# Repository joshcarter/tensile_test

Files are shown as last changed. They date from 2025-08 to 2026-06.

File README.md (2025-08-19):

# 3D Printed Plastic Tensile Strength

## Overview

I use this for measuring the tensile strength of 3D printed plastics.
There is a test fixture, an interface board, and program that runs on
a nearby laptop.

## Test Fixture

- Hi-Lift Jack
- Two clamps (see `printed_parts/Clamp.3mf`)
- 500kg S-type load cell
- HX711 load cell amplifier
- Rasperry Pi Pico interface board
- Laptop with USB connection to interface board

## Test Fixture Assembly

TODO: photo and instructions.

## Test Samples

See `printed_parts/Tensile test samples.3mf`. Note that the Z axis has
additional cross-sectional area since the Z axis is usually
substantially weaker.

## Interface Board

- Sparkfun HX711 load cell amplifier
- Raspberry Pi Pico

TODO: circuit schematic

The MicroPython code for the Pico is in the `pico` subdirectory.

## Python Requirements

    pip install -r requirements.txt

## Test Fixture Calibration

Initially the fixture will not be calibrated. Load code on the Pi Pico
(`pico/*.py) and it will output raw readings from the HX711.

Find some number of known calibration weights. I used kettlebells and
used a hanging scale to measure them as accurately as possible. These
readings (in KG) go into the `CAL_WEIGHTS` list in `utils.py`.

Run the calibration:

    python tensile_test.py calibrate --port /dev/cu.usbserial101

The first "known weight" should be no weight except the printed clamp.
Then add each known weight, pressing enter when the fixture is steady.

Finally, a `calibration.json` file will be written to this directory.
That file should be copied to the Pico. Once the Pico has its
calibration file it will output Newtons of force instead of raw HX711
readings.

## Running Tensile Tests

The main program is run like so:

    python tensile_test.py test \
      --port /dev/cu.usbserial101 \
      --type "PETG-CF" \
      --manufacturer "Atomic Filament" \
      --color "black" \
      --axis xy \

All test data will be output to a directory in the `data`
subdirectory, plus summary stats will be collected in `data/data.csv`.

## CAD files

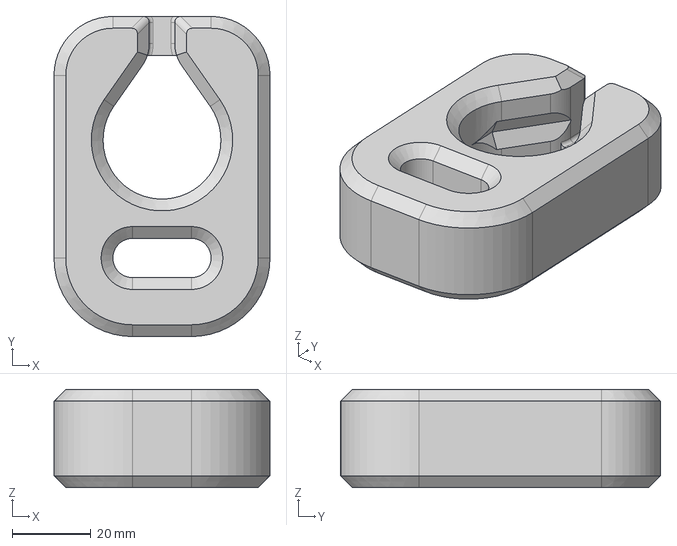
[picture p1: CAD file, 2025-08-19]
printed_parts/step/Clamp.step
55.0 x 81.5 x 25.0 mm

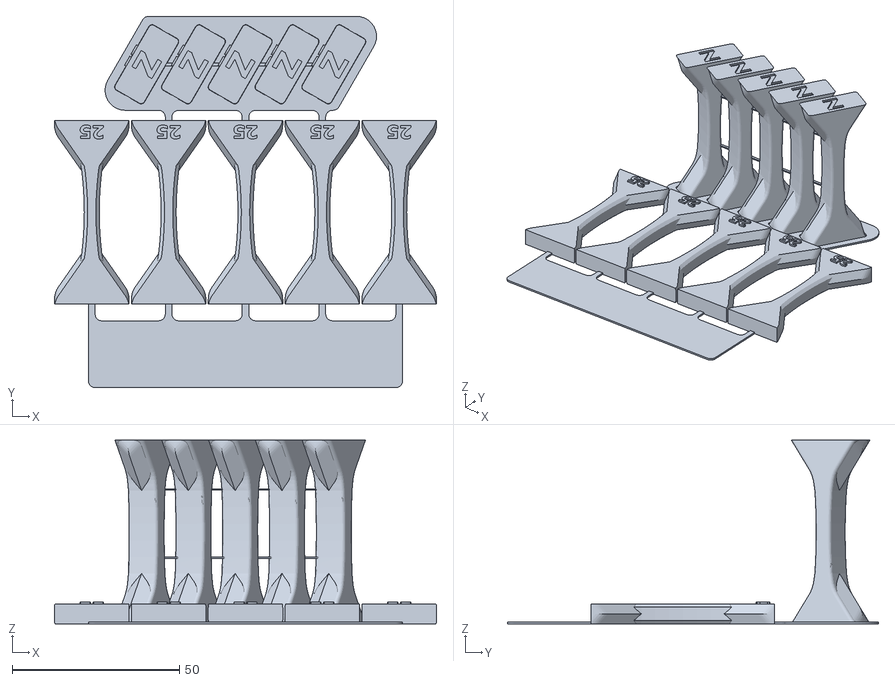
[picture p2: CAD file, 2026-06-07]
printed_parts/stl/Tensile test samples XY 25 Z 50 C.stl
114.3 x 111.1 x 55.0

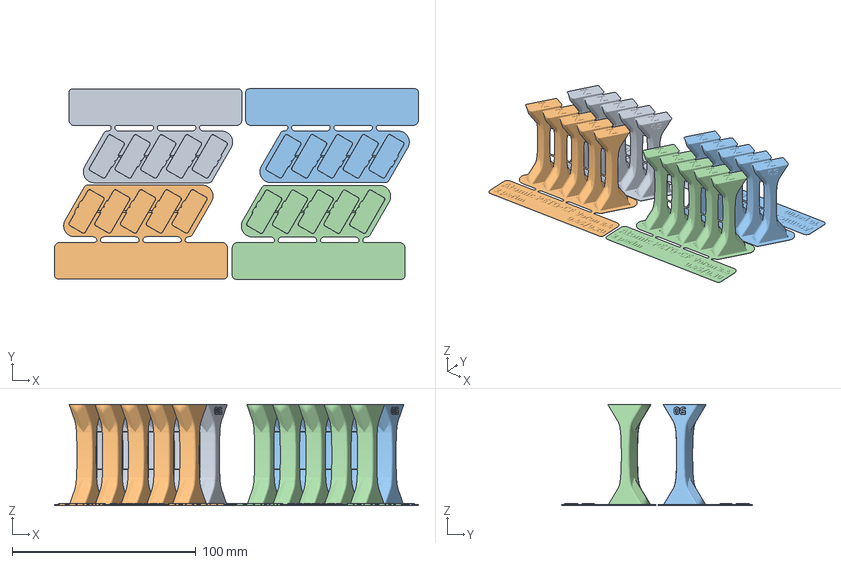
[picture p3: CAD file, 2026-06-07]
printed_parts/Tensile test samples-Z tests.3mf
197.9 x 103.6 x 55.0 mm
10 perim 0.45 0.20
2 perim 0.45 0.20
10 perim 0.45 0.10
2 perim 0.45 0.10

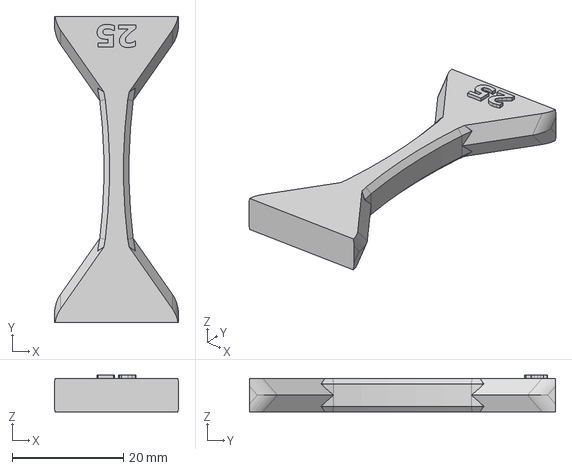
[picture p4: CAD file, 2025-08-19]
printed_parts/step/Tester XY 25mm2.step
22.3 x 55.0 x 6.60 mm

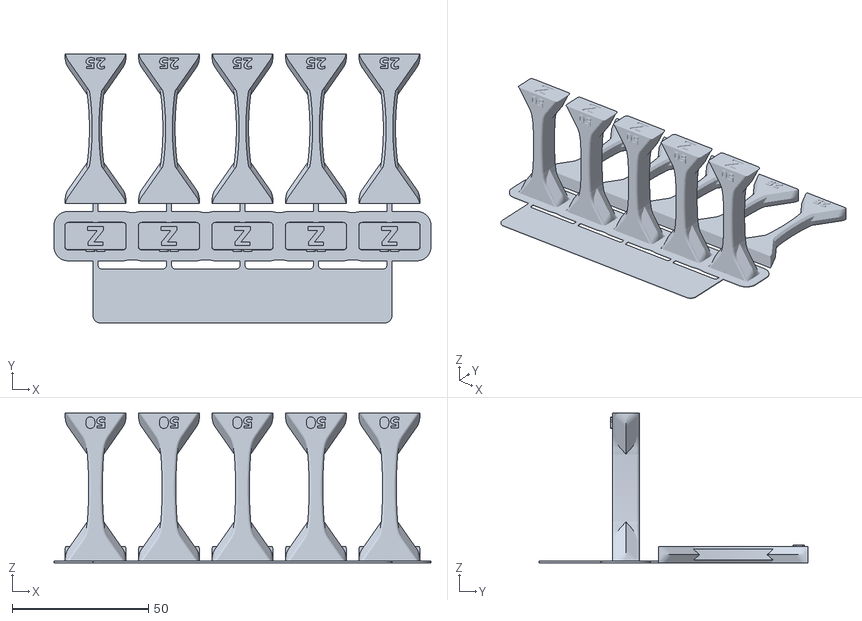
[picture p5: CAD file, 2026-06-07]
printed_parts/stl/Tensile test samples XY 25mm2 Z 50mm2 brim.stl
138.5 x 99.0 x 55.0

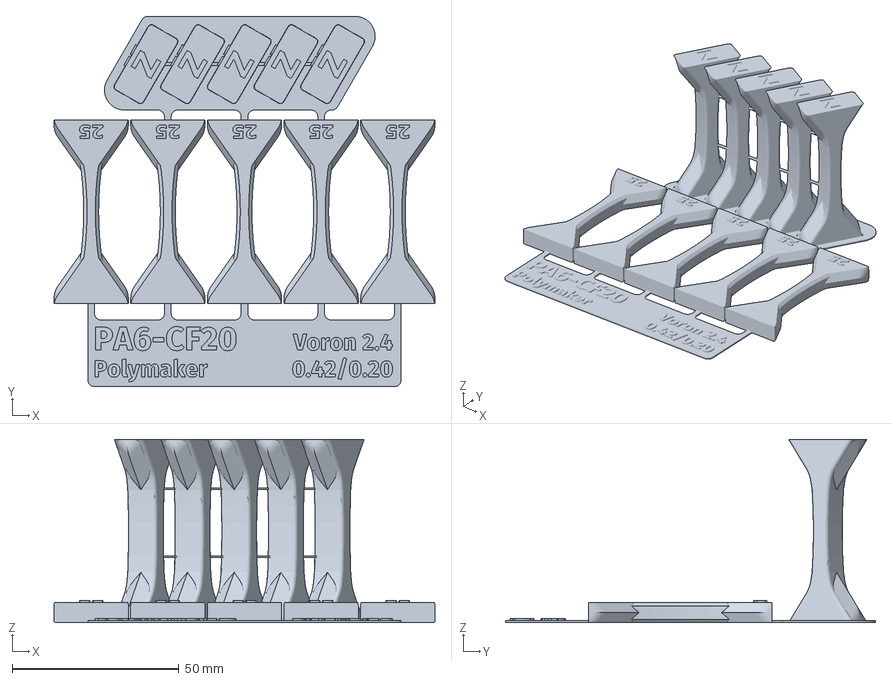
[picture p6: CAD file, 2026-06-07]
printed_parts/Tensile test samples.3mf
114.3 x 111.1 x 55.0 mm

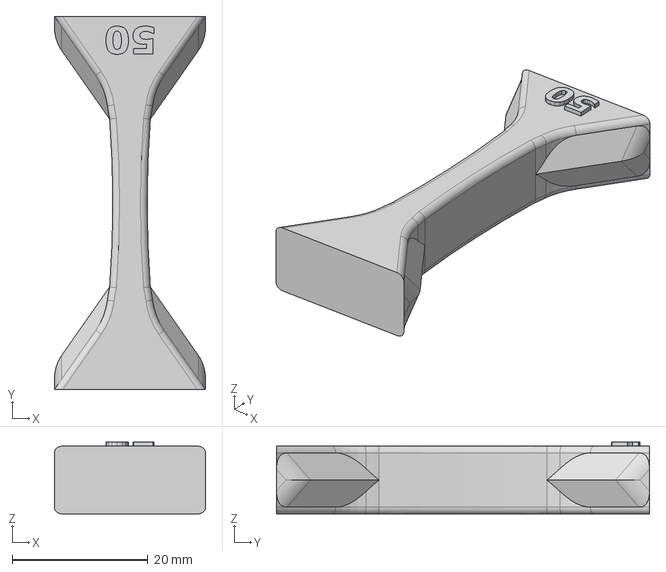
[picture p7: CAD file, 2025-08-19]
printed_parts/step/Tester Z 50mm2.step
22.3 x 55.0 x 10.6 mm

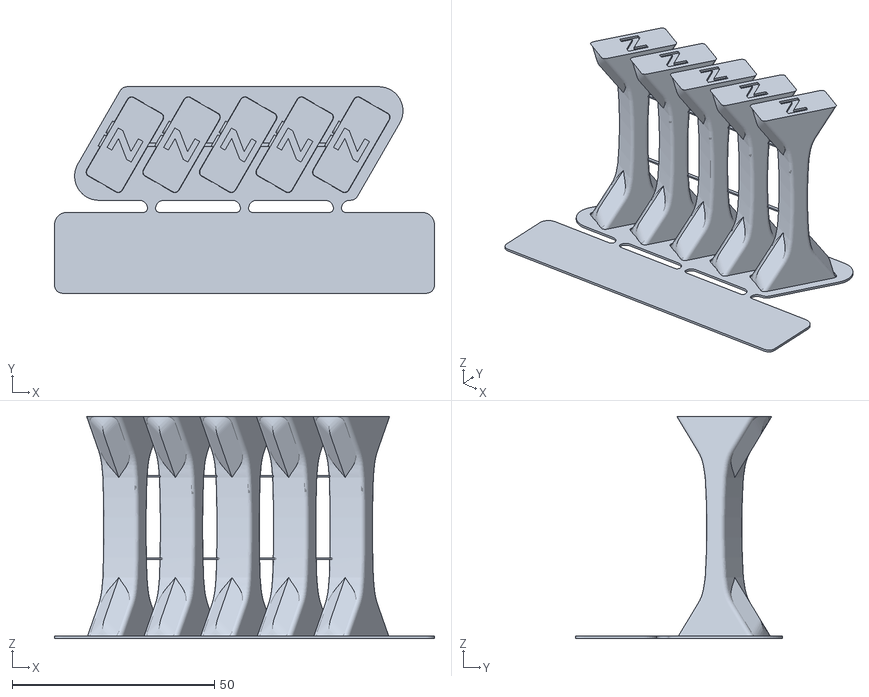
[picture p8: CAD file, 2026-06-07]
printed_parts/stl/Tensile test Z only.stl
94.0 x 51.1 x 55.0

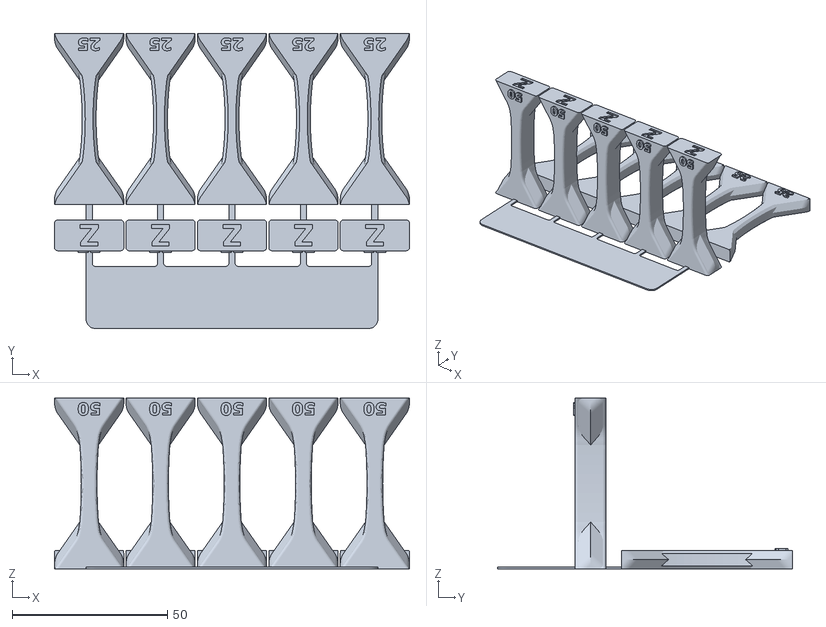
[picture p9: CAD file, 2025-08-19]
printed_parts/stl/Tensile test samples XY 25mm2 Z 50mm2.stl
114.3 x 95.0 x 55.0

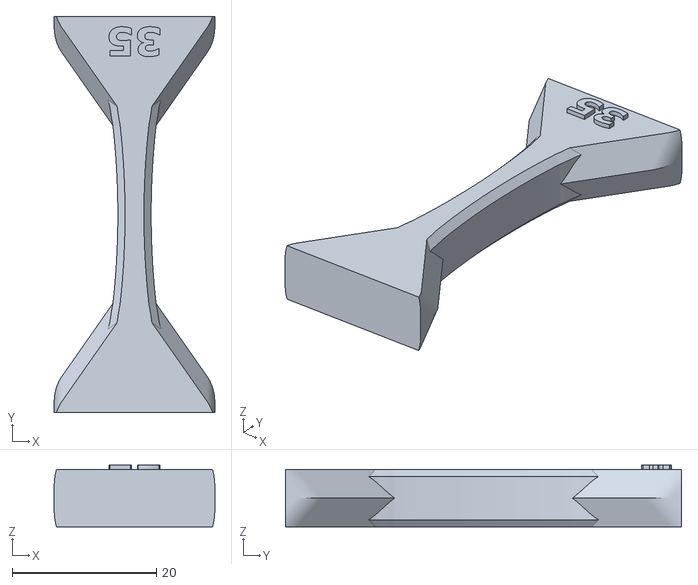
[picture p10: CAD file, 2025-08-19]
printed_parts/stl/Tester XY 35mm2.stl
22.3 x 55.0 x 8.60

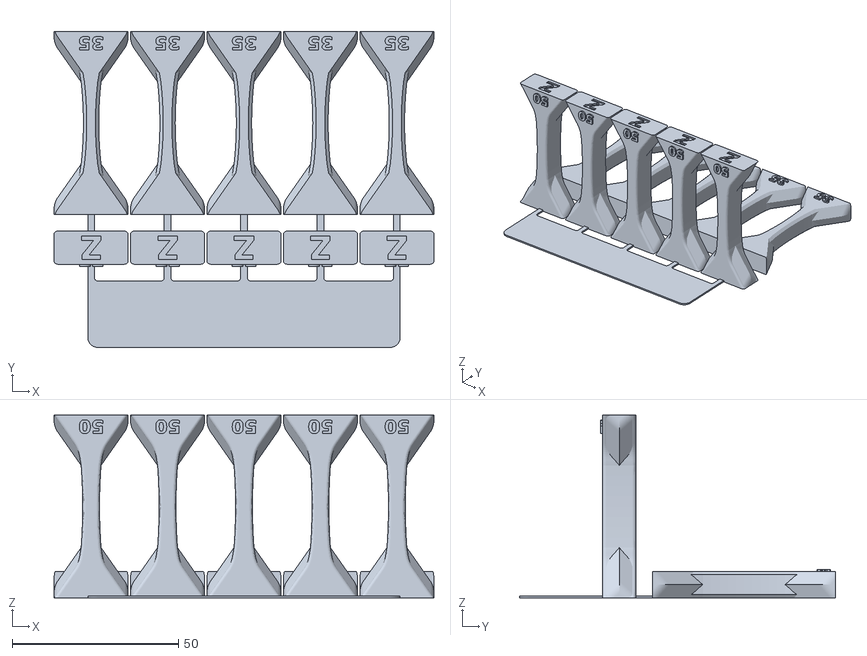
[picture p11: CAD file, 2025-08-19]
printed_parts/stl/Tensile test samples XY 35mm2 Z 50mm2.stl
114.3 x 95.0 x 55.0

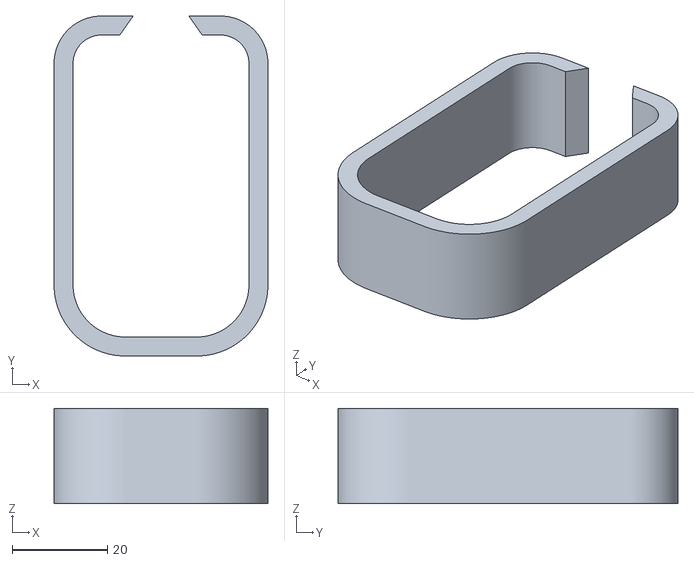
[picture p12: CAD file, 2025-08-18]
printed_parts/stl/Clamp - perim modifier.stl
45.0 x 71.5 x 20.0

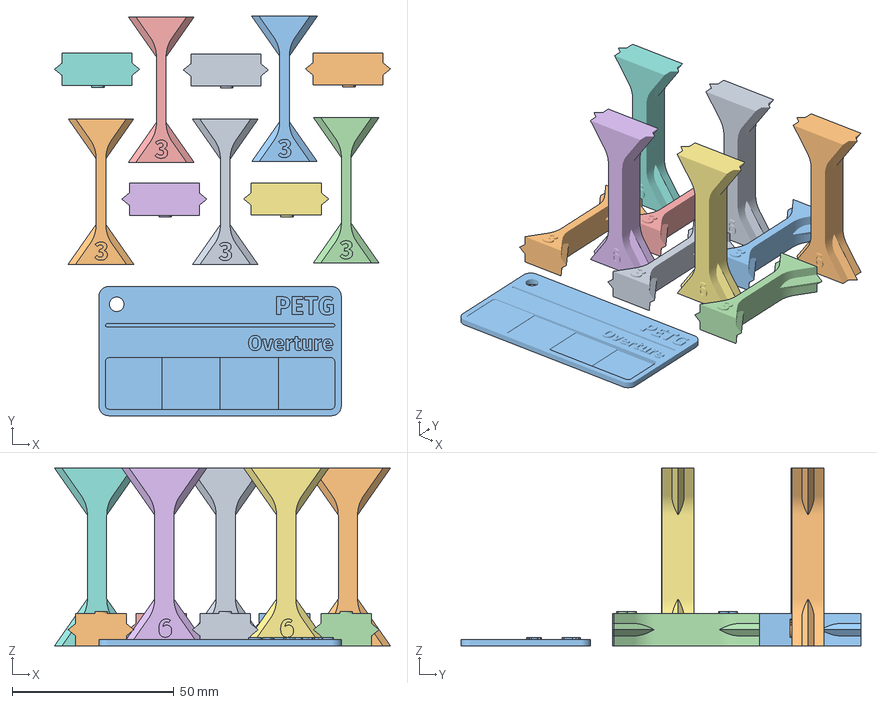
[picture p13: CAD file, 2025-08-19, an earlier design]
printed_parts/old/Tensile test samples larger [P40].3mf
104.0 x 123.6 x 55.0 mm
Tester (30mm2).stl
Tester (60mm2).stl
Sample chip

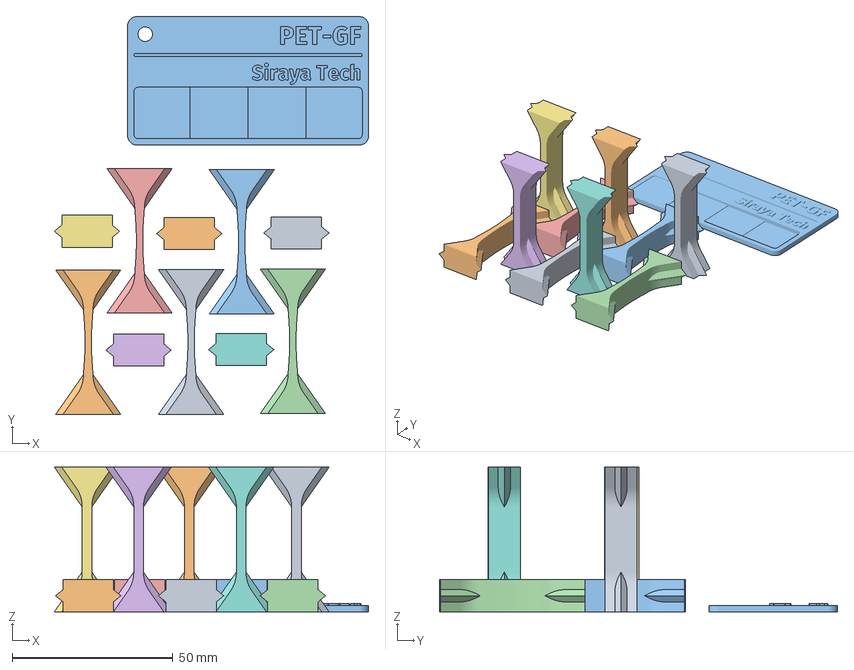
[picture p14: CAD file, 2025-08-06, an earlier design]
printed_parts/old/Tensile test samples [Mk3].3mf
97.8 x 123.8 x 45.0 mm
Tester (20mm2).stl
Tester (30mm2).stl
Sample chip

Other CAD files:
printed_parts/stl/Tensile test samples XY 25 Z 50 B.stl
printed_parts/old/Tensile test samples larger [V40].3mf
printed_parts/old/Tensile test samples larger [XL5].3mf
printed_parts/old/Tensile test samples [V40 thick extrusion].3mf
printed_parts/Clamp.3mf
printed_parts/fusion/Tensile test new design v10.f3d
printed_parts/fusion/Tensile test print setup v5.f3z
printed_parts/old/Tensile test samples [XL5].3mf
printed_parts/stl/Clamp.stl
printed_parts/stl/Tester XY 25mm2.stl
printed_parts/stl/Tester Z 50mm2.stl

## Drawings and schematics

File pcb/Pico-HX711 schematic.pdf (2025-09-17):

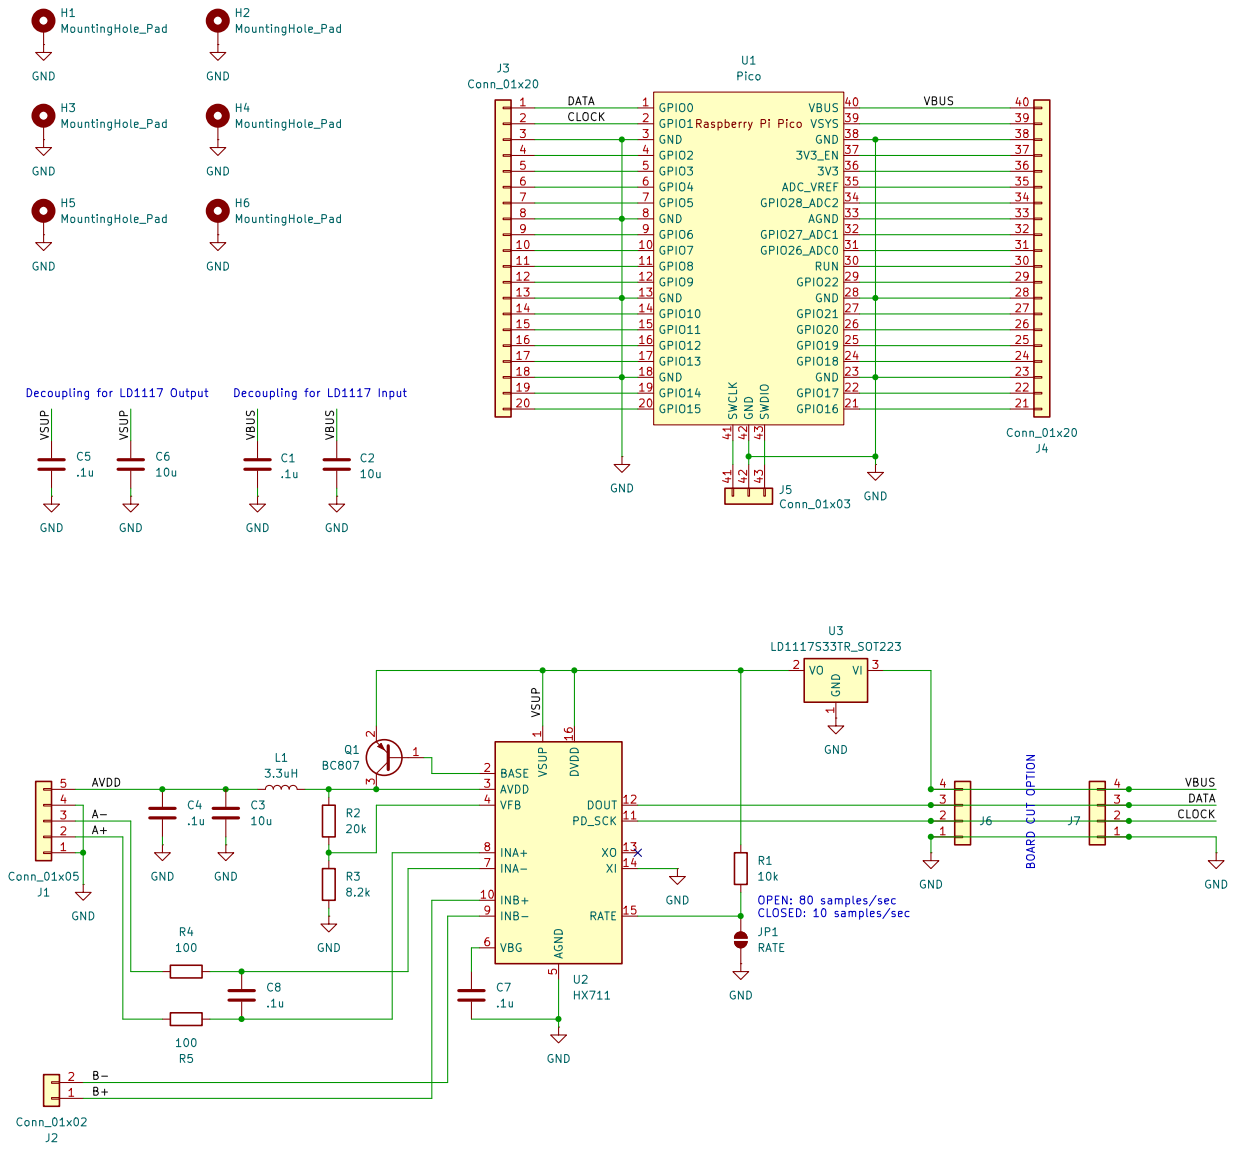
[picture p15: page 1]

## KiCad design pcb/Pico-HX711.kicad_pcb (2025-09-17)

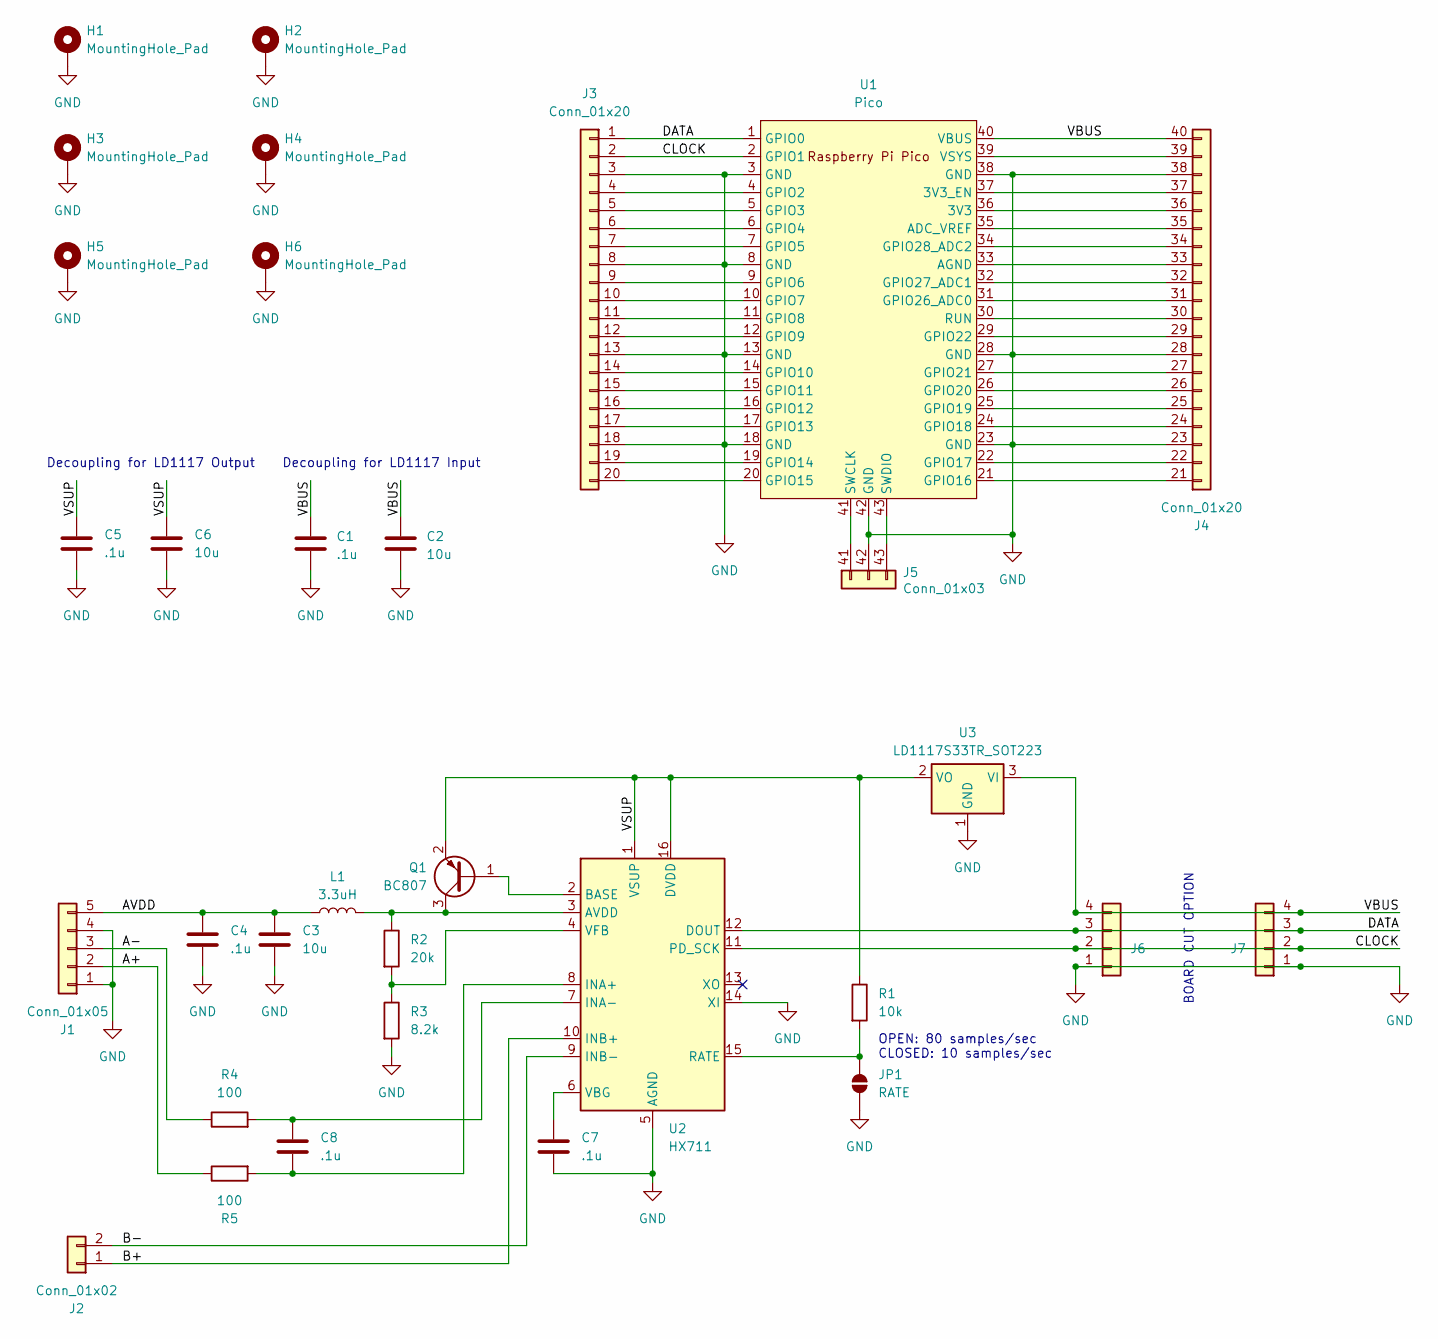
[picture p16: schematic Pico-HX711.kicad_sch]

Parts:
C1, C4, C5, C7, C8: .1u; C_0603_1608Metric
C2, C3, C6: 10u; C_1210_3225Metric
H1, H2, H3, H4, H5, H6: MountingHole_Pad; MountingHole_2.7mm_M2.5_Pad
J1: Conn_01x05; PinHeader_1x05_P2.54mm_Vertical
J2: Conn_01x02; PinHeader_1x02_P2.54mm_Vertical
J3: Conn_01x20; Pico_header_1
J4: Conn_01x20; Pico_header_2
J5: Conn_01x03; Pico_header_3
J6, J7: Conn_01x04; PinHeader_1x04_P2.54mm_Vertical
JP1: RATE; SolderJumper-2_P1.3mm_Open_RoundedPad1.0x1.5mm
L1: 3.3uH; L_0805_2012Metric
Q1: BC807; SOT-23
R1: 10k; R_0603_1608Metric
R2: 20k; R_0603_1608Metric
R3: 8.2k; R_0603_1608Metric
R4, R5: 100; R_0603_1608Metric
U1: Pico; RPi_Pico_SMD_TH
U2: HX711; SOIC-16_3.9x9.9mm_P1.27mm
U3: LD1117S33TR_SOT223; SOT-223-3_TabPin2

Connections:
/A+: J1.2, R5.1
/A-: J1.3, R4.1
/AVDD: C3.1, C4.1, J1.5, L1.1
/B+: J2.1, U2.10 (INB+)
/B-: J2.2, U2.9 (INB-)
/CLOCK: J3.2, J6.2, J7.2, U1.2 (GPIO1), U2.11 (PD_SCK)
/DATA: J3.1, J6.3, J7.3, U1.1 (GPIO0), U2.12 (DOUT)
/VBUS: C1.2, C2.2, J4.40 (Pin_20), J6.4, J7.4, U1.40 (VBUS), U3.3 (VI)
/VSUP: C5.1, C6.1, Q1.2 (E), R1.1, U2.1 (VSUP), U2.16 (DVDD), U3.2 (VO)
GND: C1.1, C2.1, C3.2, C4.2, C5.2, C6.2, C7.2, H1.1, H2.1, H3.1, H4.1, H5.1, H6.1, J1.1, J1.4, J3.3, J3.8, J3.13, J3.18, J4.23 (Pin_3), J4.28 (Pin_8), J4.38 (Pin_18), J5.42 (Pin_2), J6.1, J7.1, JP1.1 (A), R3.2, U1.3 (GND), U1.8 (GND), U1.13 (GND), U1.18 (GND), U1.23 (GND), U1.28 (GND), U1.38 (GND), U1.42 (GND), U2.5 (AGND), U2.14 (XI), U3.1 (GND)
unnamed: J3.4, U1.4 (GPIO2)
unnamed: J3.5, U1.5 (GPIO3)
unnamed: J3.6, U1.6 (GPIO4)
unnamed: J3.7, U1.7 (GPIO5)
unnamed: J3.9, U1.9 (GPIO6)
unnamed: J3.10, U1.10 (GPIO7)
unnamed: J3.11, U1.11 (GPIO8)
unnamed: J3.12, U1.12 (GPIO9)
unnamed: J3.14, U1.14 (GPIO10)
unnamed: J3.15, U1.15 (GPIO11)
unnamed: J3.16, U1.16 (GPIO12)
unnamed: J3.17, U1.17 (GPIO13)
unnamed: J3.19, U1.19 (GPIO14)
unnamed: J3.20, U1.20 (GPIO15)
unnamed: J4.21 (Pin_1), U1.21 (GPIO16)
unnamed: J4.22 (Pin_2), U1.22 (GPIO17)
unnamed: J4.24 (Pin_4), U1.24 (GPIO18)
unnamed: J4.25 (Pin_5), U1.25 (GPIO19)
unnamed: J4.26 (Pin_6), U1.26 (GPIO20)
unnamed: J4.27 (Pin_7), U1.27 (GPIO21)
unnamed: J4.29 (Pin_9), U1.29 (GPIO22)
unnamed: J4.30 (Pin_10), U1.30 (RUN)
unnamed: J4.31 (Pin_11), U1.31 (GPIO26_ADC0)
unnamed: J4.32 (Pin_12), U1.32 (GPIO27_ADC1)
unnamed: J4.33 (Pin_13), U1.33 (AGND)
unnamed: J4.34 (Pin_14), U1.34 (GPIO28_ADC2)
unnamed: J4.35 (Pin_15), U1.35 (ADC_VREF)
unnamed: J4.36 (Pin_16), U1.36 (3V3)
unnamed: J4.37 (Pin_17), U1.37 (3V3_EN)
unnamed: J4.39 (Pin_19), U1.39 (VSYS)
unnamed: J5.41 (Pin_1), U1.41 (SWCLK)
unnamed: J5.43 (Pin_3), U1.43 (SWDIO)
unnamed: JP1.2 (B), R1.2, U2.15 (RATE)
unnamed: Q1.1 (B), U2.2 (BASE)
unnamed: L1.2, Q1.3 (C), R2.1, U2.3 (AVDD)
unnamed: C8.2, R5.2, U2.8 (INA+)
unnamed: C8.1, R4.2, U2.7 (INA-)
unnamed: C7.1, U2.6 (VBG)
unnamed: R2.2, R3.1, U2.4 (VFB)

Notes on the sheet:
BOARD CUT OPTION
OPEN: 80 samples/sec CLOSED: 10 samples/sec
Decoupling for LD1117 Output
Decoupling for LD1117 Input

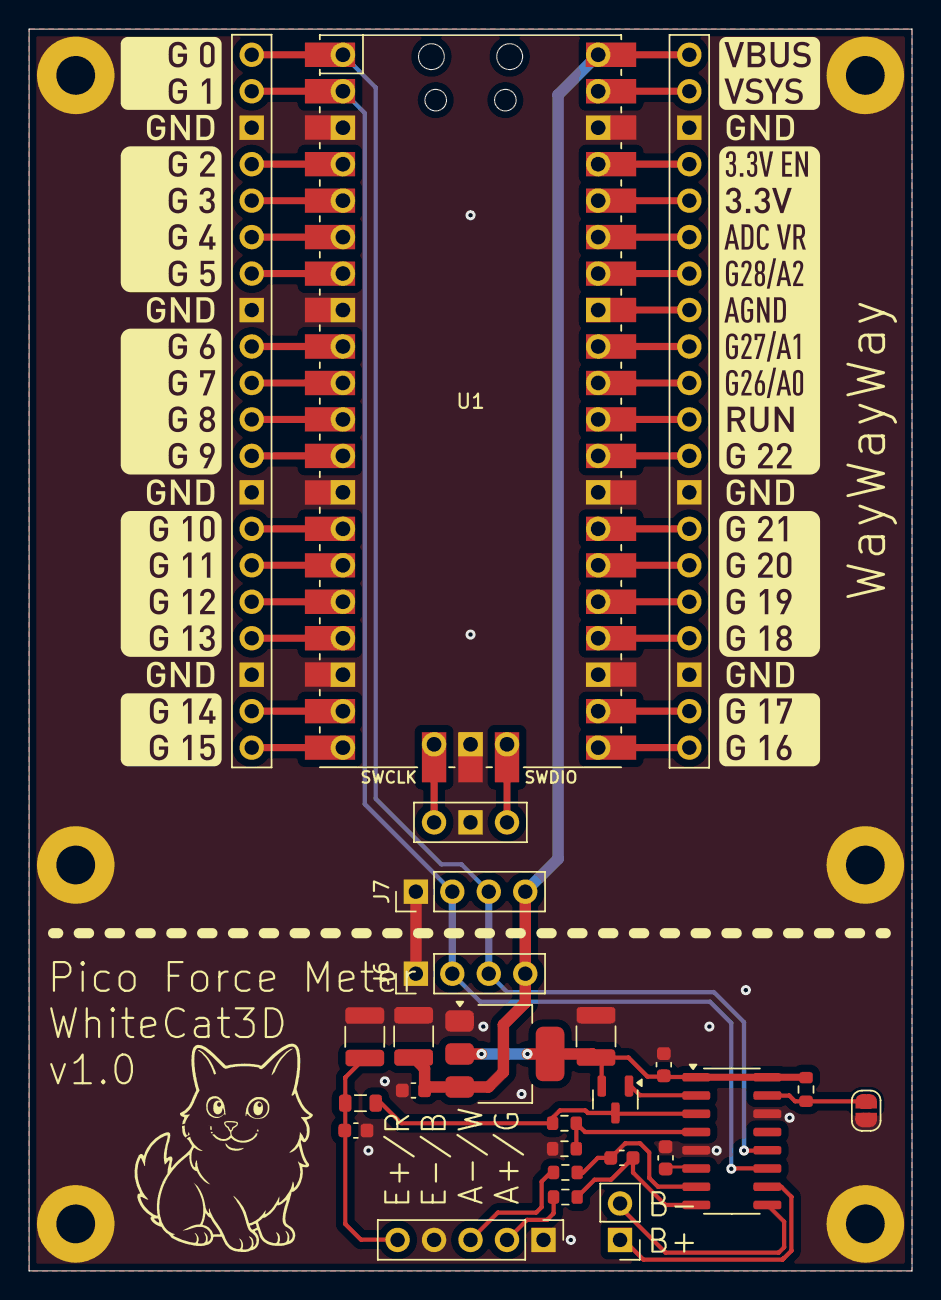
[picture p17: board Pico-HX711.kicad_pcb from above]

Board: 2 copper layers, 61.5 x 86.5 mm, 32 parts (0 on the bottom side), 49 nets.

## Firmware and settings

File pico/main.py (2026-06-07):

import time
import gc
import board
import digitalio
import usb_cdc
import json

last_reading = 0
MAX_CODE = 0x7FFFFF
MIN_CODE = -0x800000

class HX711:
    def __init__(self, dout, pd_sck, gain=128):
        self.pSCK = digitalio.DigitalInOut(pd_sck)
        self.pOUT = digitalio.DigitalInOut(dout)
        self.pSCK.direction = digitalio.Direction.OUTPUT
        self.pOUT.direction = digitalio.Direction.INPUT
        self.gain = gain
        self.offset = 0
        self.reset()

    def reset(self):
        # Reset HX711: hold PD_SCK high >60us to trigger power-down + reset,
        # then bring it back low to power up.
        self.pSCK.value = True
        time.sleep(0.0001)
        self.pSCK.value = False
        time.sleep(0.0001)

    def is_ready(self):
        return not self.pOUT.value

    def read(self, timeout_ms=100):
        # Wait for ready with timeout
        start_ms = time.monotonic() * 1000
        while not self.is_ready():
            if (time.monotonic() * 1000) - start_ms > timeout_ms:
                self.reset()
                return None  # Return None on timeout
            time.sleep(0.0001)

        # Disable GC so a collection pause can't stall us mid-shift. If PD_SCK
        # is held high for >60us the HX711 powers down and corrupts the read,
        # which shows up as occasional large spikes in the data.
        gc.disable()
        try:
            # Read 24 bits
            result = 0
            for _ in range(24):
                self.pSCK.value = True
                result = result << 1
                self.pSCK.value = False
                if self.pOUT.value:
                    result += 1

            # Set gain for next reading
            for _ in range(1 if self.gain == 128 else 2 if self.gain == 32 else 3):
                self.pSCK.value = True
                self.pSCK.value = False
        finally:
            gc.enable()

        # Convert from 2's complement
        if result & 0x800000:
            result -= 0x1000000

        # Clamp values
        return max(MIN_CODE, min(MAX_CODE, result))

# Initialize
hx = HX711(board.GP0, board.GP1)
serial = usb_cdc.data
serial.timeout = 0


# ——— Try Load Calibration ———
use_newtons = False
offset = 0.0
slope = 1.0
try:
    with open("calibration.json", "r") as f:
        cal = json.load(f)
        offset = float(cal["offset"])
        slope  = float(cal["slope"])
        use_newtons = True
except Exception:
    # no file or parse error → stick to raw counts
    use_newtons = False


# Main loop with error handling
error_count = 0
last_send_time = time.monotonic()

while True:
    try:
        # Rate limiting
        now = time.monotonic()
        if now - last_send_time < 0.01:  # Max 100Hz instead of 1000Hz
            continue

        reading = hx.read(timeout_ms=50)

        if reading is not None:
            if use_newtons:
                N = (reading - offset) / slope
                serial.write(f"{N:.3f}N\n".encode("utf-8"))
            else:
                serial.write(f"{reading}\n".encode("utf-8"))
            last_send_time = now
            error_count = 0
        else:
            error_count += 1
            if error_count > 10:
                print("reseting hx711")
                # Too many errors, reset HX711
                hx.reset()
                error_count = 0

    except Exception as e:
        print(f"Error: {e}")
        time.sleep(0.1)  # Back off on errors

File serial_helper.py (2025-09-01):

import serial
from collections import deque
import os, sys
import time


def _find_available_port(preferred_port=None):
    """
    Find an available serial port, trying preferred_port first if specified.
    Returns the port path or None if no port found.
    """
    ports_to_try = []
    
    # If a preferred port is specified, try it first
    if preferred_port:
        ports_to_try.append(preferred_port)
    
    # Add default ports to try
    default_ports = ["/dev/cu.usbmodem103", "/dev/cu.usbmodem1103", "/dev/cu.usbmodem13103", "/dev/serial1", "/dev/cu.usbmodem11203"]
    for port in default_ports:
        if port not in ports_to_try:
            ports_to_try.append(port)
    
    for port in ports_to_try:
        if os.path.exists(port):
            return port
    
    return None


class SerialMovingAverageReader:
    """
    A helper class to read a stream of values from a serial port and return a smoothed average.
    Can handle both raw counts (integers) and Newton values (floats with 'N' suffix).
    """

    def __init__(self, port, baud=115200, timeout=0.1, window_size=3):
        """
        :param port:      Serial port device (e.g. '/dev/ttyACM1')
        :param baud:      Baud rate (must match Pico)
        :param timeout:   Read timeout in seconds
        :param window_size: Number of samples to average
        """
        # Use utility function to find available port
        found_port = _find_available_port(port)
        if found_port is None:
            print(f"Error: Serial port cannot be determined; specify with --port")
            sys.exit(1)
        port = found_port

        # Store connection parameters for recovery
        self.port = port
        self.baud = baud
        self.timeout = timeout
        self.recovery_attempts = 0
        self.max_recovery_attempts = 3
        self.consecutive_errors = 0
        self.max_consecutive_errors = 10  # Trigger clean exit after this many errors
        
        self.ser = serial.Serial(port, baud, timeout=timeout)
        self.buffer = deque(maxlen=window_size)
        # Open error log file for logging invalid reads
        self.log_file = open("serial_errors.log", "a")

    def reset(self):
        """Reset the serial buffer."""
        self.buffer.clear()
        if self.ser and self.ser.is_open:
            self.ser.reset_input_buffer()
            
    def _recover_connection(self):
        """
        Attempt to recover the serial connection by closing and reopening the port.
        If the current port is no longer available, scan for available ports.
        Returns True if recovery successful, False otherwise.
        """
        if self.recovery_attempts >= self.max_recovery_attempts:
            self._log_error(f"Max recovery attempts ({self.max_recovery_attempts}) reached")
            return False
            
        self.recovery_attempts += 1
        self._log_error(f"Attempting connection recovery #{self.recovery_attempts}")
        
        try:
            # Close existing connection
            if self.ser and self.ser.is_open:
                self.ser.close()
                
            # Wait a moment before reopening
            time.sleep(0.1)
            
            # Find available port (may be different if device was unplugged/replugged)
            recovery_port = _find_available_port(self.port)
            if recovery_port is None:
                self._log_error(f"No available serial ports found during recovery")
                return False
                
            # Update stored port if it changed
            if recovery_port != self.port:
                self._log_error(f"Port changed from {self.port} to {recovery_port}")
                self.port = recovery_port
            
            # Reopen connection
            self.ser = serial.Serial(self.port, self.baud, timeout=self.timeout)
            self._log_error(f"Connection recovery #{self.recovery_attempts} successful on {self.port}")
            
            # Reset error counter on successful recovery
            self.consecutive_errors = 0
            return True
            
        except Exception as e:
            self._log_error(f"Connection recovery #{self.recovery_attempts} failed: {e}")
            return False

    def _log_error(self, message):
        """Log error message with timestamp to log file."""
        from datetime import datetime
        timestamp = datetime.now().isoformat()
        self.log_file.write(f"{timestamp} - {message}\n")
        self.log_file.flush()

    def _read_line(self):
        """Read one line from the serial port with automatic recovery on errors."""
        for attempt in range(2):  # Try twice: initial attempt + one retry after recovery
            try:
                line = self.ser.readline().decode(errors="ignore").strip()
                # Reset counters on successful read
                self.consecutive_errors = 0
                self.recovery_attempts = 0
                return line
            except Exception as e:
                self.consecutive_errors += 1
                self._log_error(f"Error reading line (error #{self.consecutive_errors}): {e}")
                
                # Only attempt recovery on first failure (attempt 0)
                if attempt == 0 and not self._recover_connection():
                    break  # Recovery failed, don't retry
                    
        return None

    def read_raw_counts(self):
        """
        Read one raw count value from the serial port.
        Expects integer values with no suffix.
        Raises ValueError if Newton values are detected.
        """
        line = self._read_line()
        if not line:
            self._log_error("Empty line received")
            return None

        # Check if this is a Newton value (has 'N' suffix)
        if line.endswith('N'):
            raise ValueError(
                "ERROR: Pico is sending calibrated Newton values when raw counts are expected. "
                "The Pico should not have a calibration.json file during calibration mode."
            )

        try:
            # Try to parse as integer first (expected format)
            return float(int(line))
        except ValueError:
            try:
                # Fall back to float if it's a decimal raw value
                return float(line)
            except ValueError as e:
                self._log_error(f"ValueError parsing raw count from line: {line} - {e}")
                return None

    def read_newtons(self):
        """
        Read one Newton value from the serial port.
        Expects float values with 'N' suffix.
        Raises ValueError if raw counts are detected.
        """
        line = self._read_line()
        if not line:
            self._log_error("Empty line received")
            return None
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

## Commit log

2025-08-03 working on calibration
    [calibration-0.0.csv, calibration-16.0.csv, calibration-31.6.csv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]
2025-08-03 Adding printed parts and current data.
    [Clamp - perim modifier.stl, Clamp.stl, Polymaker-PET-CF-xy-1.csv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]
2025-08-03 removing old arduino code; renaming Pico MicroPython code.
2025-08-03 Better logging and summary result printing.
2025-08-03 fixed calibration (?)
2025-08-03 switching calibration to linear regression.
2025-08-03 new calibration.json with 80hz hx711.
2025-08-03 Polymaker PET-CF
    [Polymaker-PET-CF-xy-1.csv, Polymaker-PET-CF-xy-2.csv, Polymaker-PET-CF-xy-3.csv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]
2025-08-03 adding more test data.
    [Tensile test samples.3mf, data.csv]
2025-08-04 adding config reader, new data columns.
    [data.csv]
2025-08-04 bug fix for serial reader
    [tensile_test.py]
2025-08-05 more data
    [data.csv]
2025-08-06 updated printed parts; larger clamp variant
    [Clamp (20-30mm2) perim modifier.stl, Clamp (20-30mm2).3mf, Clamp (20-30mm2).stl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]
2025-08-07 working on new pico code.
2025-08-08 fixing pico code.
2025-08-08 improving pico code
2025-08-08 fixing serial stalls on pico
    [main.py]
2025-08-08 fixing issue in calibrate on bad serial read.
    [calibration-0.0.csv, calibration-16.0.csv, calibration-31.6.csv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]
2025-08-08 integrating with changes in pico serial data.
2025-08-08 adding current version of python code.
2025-08-09 adding more test results
    [SirayaTech-PET-GF-xy-1.csv, SirayaTech-PET-GF-xy-2.csv, SirayaTech-PET-GF-xy-3.csv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]
2025-08-09 removing some old data
    [SirayaTech-PET-GF-xy-1.csv, SirayaTech-PET-GF-xy-2.csv, SirayaTech-PET-GF-xy-3.csv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]
2025-08-09 fixes in test app.
    [tensile_test.py, test_app.py]
2025-08-12 working on cleaner handling of serial resets.
    [Tensile test samples.3mf, Tensile testers XY-25 Z-50.stl, data.csv]
2025-08-17 code refactoring and updated 50/25mm2 printed parts.
    [Tensile test samples [Mk3].3mf, Tensile test samples [V40 thick extrusion].3mf, Tensile test samples [XL5].3mf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]
2025-08-18 New test data; fixing regression in test_app.
    [Clamp (20-30mm2) perim modifier.stl, Clamp (20-30mm2).3mf, Clamp (20-30mm2).stl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]
2025-08-18 New test sample and clamp design
    [Clamp - perim modifier.stl, Clamp.3mf, Clamp.stl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]
2025-08-18 Siraya Tech ASA-GF
    [data.csv]
2025-08-19 test samples with fewer sprues.
    [Tensile test samples.3mf, Tensile test samples.stl]
2025-08-19 moving STLs into their own directory.
    [Clamp - perim modifier.stl, Clamp.stl, Tensile test samples.stl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]
2025-08-19 updating printed parts
    [Clamp.3mf, Tensile test new design v10.f3d, Tensile test print setup v5.f3z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]
2025-08-19 adding STEP for clamp.
    [Clamp.step]
2025-08-24 minor mods
    [Tensile test samples.3mf]
2025-08-25 more test data on PLA variants
    [data.csv]
2025-08-30 test data for ABS, ASA with CF and GF
    [data.csv]
2025-09-01 adding newest round of PET test data.
    [Tensile test samples.3mf, data.csv]
2025-09-01 ordering test data by XY tensile strength
    [data.csv]
2025-09-08 data for PETG in 4 colors; new tester with Z axis brim.
    [Tensile test samples.3mf, data.csv]
2025-09-11 more test data
    [data.csv]
2025-09-17 Adding PCB.
    [Pico-HX711.kicad_pcb, Pico-HX711.kicad_sch]
2026-05-30 test data
    [Tensile test samples.3mf, data.csv]
2026-06-07 New test sample parts.
    [Tensile test Z only.stl, Tensile test samples XY 25 Z 50 B.stl, Tensile test samples XY 25 Z 50 C.stl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]
2026-06-07 New pico code to fix intermittent HX711 invalid read errors.
    [main.py]
